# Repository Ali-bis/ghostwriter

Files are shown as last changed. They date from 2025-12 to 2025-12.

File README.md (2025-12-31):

🖋️ Ghost Writer - A Custom PCB Pen Plotter
Ghost Writer is a precision pen plotter that can be used to solve the "messy wiring" problem you usually get when you build one of those open-source plotter kits. To make that happen, I built a custom board that works with a compact - and 3D printed - parallel linkage gantry, which gives Ghost Writer high-torque motion control in a tiny footprint.

Figure 1: The Final Assembled Project, shown in CAD
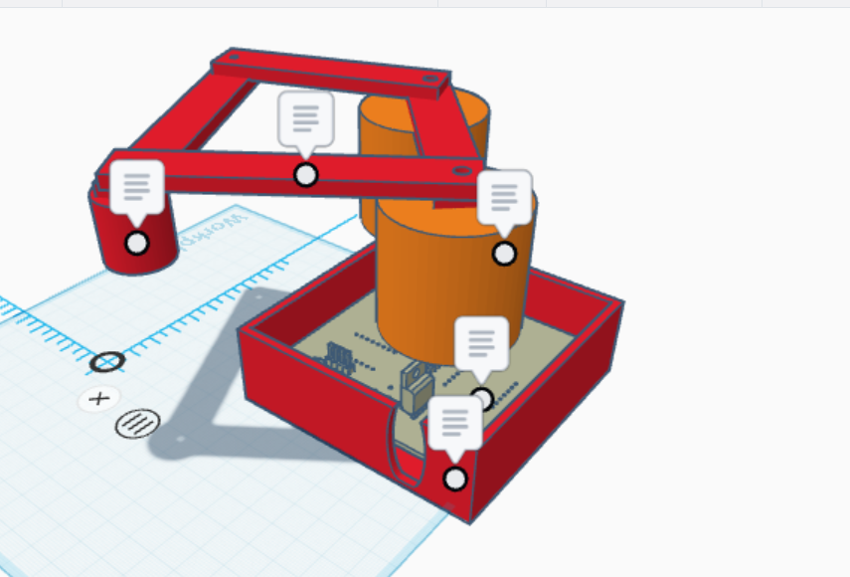
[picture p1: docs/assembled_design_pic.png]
assembled pic

assembled vid
🚀 Why I Did This
Most open-source kits have a problem with cable management and getting the electronics to work together without breaking. Ghost Writer was made to move away from the "breadboard prototype" stage and into something a bit more robust.

What I Wanted to Achieve:
No More Messy Wiring: A custom PCB means you can ditch the jumper wires and use dedicated traces for power and signal instead.
It's Super Compact: A custom 3D printed enclosure with a special cable management system keeps the whole thing at a tiny 30mm high.
It Draws Precisely: Powered by high-torque NEMA 17 steppers and a Seeed Studio XIAO (RP2040) for real-time inverse kinematics - that's a mouthful, but basically it draws very nicely.

🛠️ Hardware
Here are the key bits that make Ghost Writer tick
Main Processor: Seeed Studio XIAO RP2040 (a dual-core ARM Cortex M0+ processor)
Motion: 2x NEMA 17 Stepper Motors (each one with a 1.8° step angle for smooth movement)
Motor Drivers: 2x A4988 Stepper Drivers (these are super powerful and tuned to get the most out of the motors)
Pen Lift: a SG90 Micro Servo that you can control with a pulse-width modulation signal
Display: A tiny 0.96" I2C OLED Display so you can keep an eye on what's going on and where things are moving to
Power: 12V 2A DC via a standard barrel jack

🏗️ Mechanical Design & CAD
The enclosure was designed in Tinkercad with one main goal - stop the mechanical bits getting in the way of each other.
Carrier Board Mounting: the PCB is held in place with 9mm internal pillars which keeps it nice and insulated from the rest of the robot.
Parallel Linkage: the 80mm shoulder and 100mm forearm lengths give it a pretty generous drawing area for its size
U-Slot Management: a special cable path keeps the wiring clear of the moving parts
Figure 2: a clearance check between the custom PCB and the 3D printed housing

📂 Repository Structure
├── /hardware\
│   ├── /pcb        # the KiCad board files and Fabrication outputs (Gerbers)\
│   ├── /enclosure  # the STL files for the Box, Lid, and Linkage Arms\
│   └── /firmware   # the custom C++ validation suite (GhostWriter_Test)\
├── BOM.csv         # the Bill of Materials (itemised costs and links)\
└── README.md       # the Project documentation\

📋 Bill of Materials
The breakdown of costs and sourcing is in the BOM.csv file.
Note: This project tried to stay within a $100 budget by doing some creative 3D printing and choosing shipping methods that are pretty cost-effective

⚙️ Firmware
The system is currently running a custom C++ validation suite (GhostWriter_Test) to get the motors and servo working smoothly.
At the moment: I'm still working on getting G-Code interpretation via GRBL for RP2040 to work properly.
Motion Logic: the inverse kinematics calculations are being done on the second core of the RP2040 so the motor pulses are nice and smooth.
A Sneak Peek at the Design

Figure 2: Just to be sure - I checked to see if the PCB would fit inside the enclosure
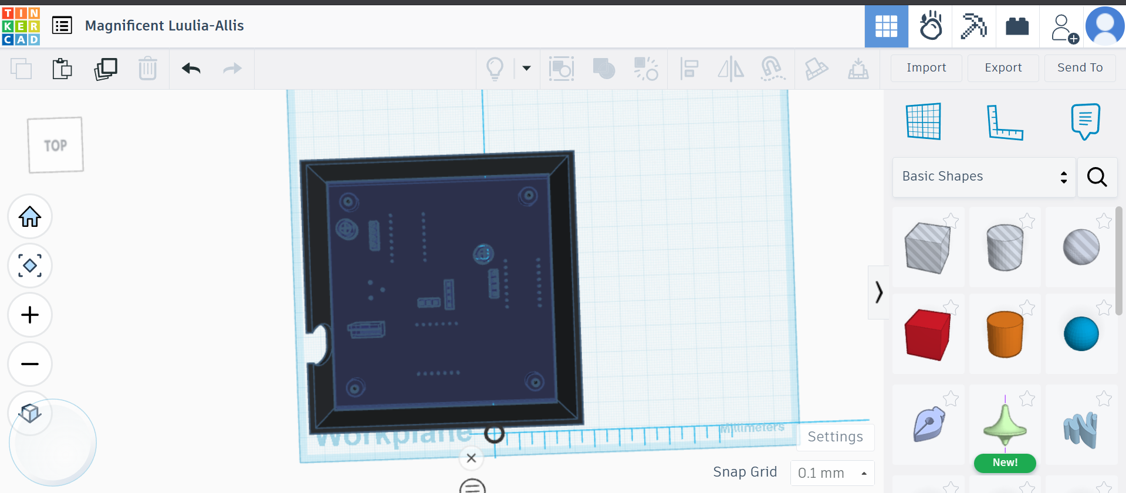
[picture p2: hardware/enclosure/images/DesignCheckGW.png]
EnclosureCheck


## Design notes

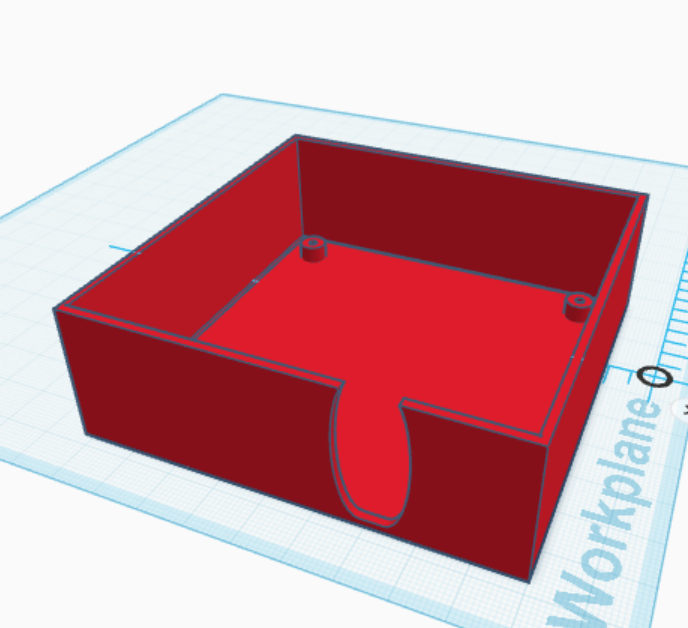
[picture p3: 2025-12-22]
docs/enclosure_design.png

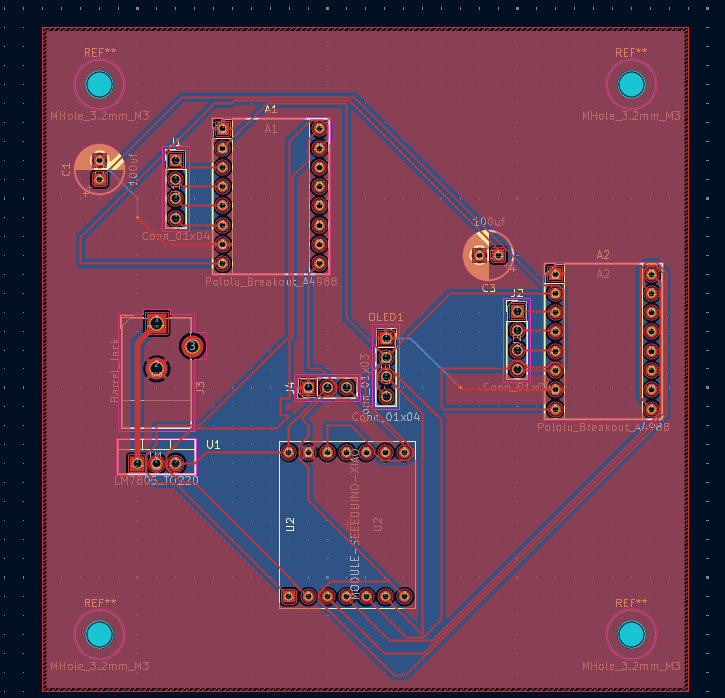
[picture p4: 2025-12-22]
docs/pcb_layout.png

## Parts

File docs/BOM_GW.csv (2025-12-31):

Item | Category | Description | Qty | Price (INR) | Sourcing Link
Seeed Studio XIAO RP2040 | Controller | Dual-core ARM Cortex M0+ | 1 | 1320 | Amazon
NEMA 17 Stepper Motors | Actuators | High Torque (Pack of 2) | 1 | 1550 | Amazon
A4988 Stepper Drivers | Electronics | With Heatsink | 2 | 598 | Amazon
0.96" I2C OLED Display | UI | 128x64 Blue/Yellow | 1 | 449 | Amazon
12V 2A DC Adapter | Power | Barrel Jack Supply | 1 | 299 | Amazon
SG90 Micro Servo | Actuator | 9g Pen-lift (Pack of 2) | 1 | 319 | Amazon
M3/M4/M5 Hardware Kit | Mechanical | Stainless Steel (280 pcs) | 1 | 1150 | Amazon
Themisto TH-B400 | Prototyping | 400 Tie Point Breadboard | 1 | 158 | Amazon
Jumper Wire Set | Wiring | 120 pcs (MM/MF/FF) | 1 | 198 | Amazon
Custom PCB | PCB | Fabricated by Lion Circuits | 1 | 1589 | Lion Circuits
DC Barrel Jack Adapter | Power | Female to Screw Terminal | 1 | 50 | Amazon
 |  | TOTAL |  | ₹8278

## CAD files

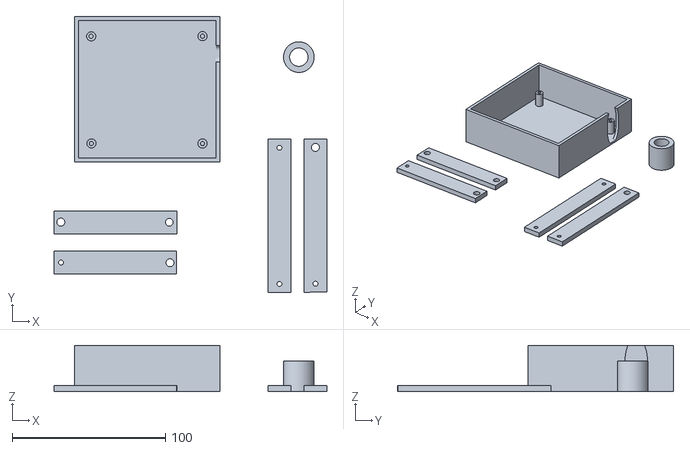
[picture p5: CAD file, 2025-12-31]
hardware/enclosure/stl/ghostwriter parts flat.stl
178.0 x 179.9 x 30.0

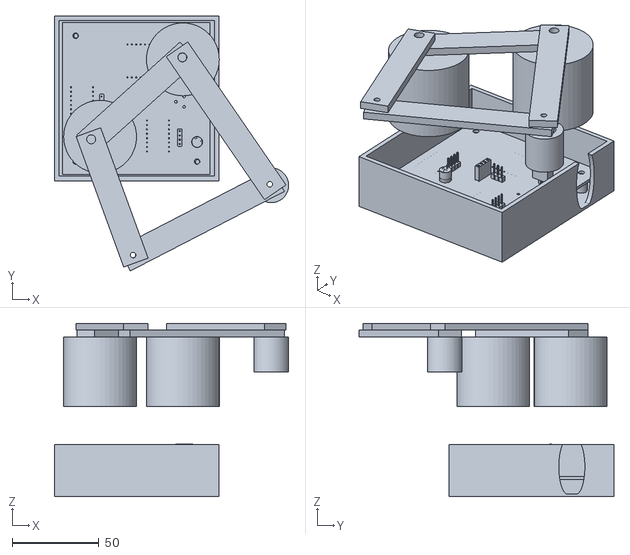
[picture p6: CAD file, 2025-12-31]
hardware/enclosure/stl/Final_design_GW (NOT TO BE PRINTED - ONLY REF OF FINAL MODEL) .stl
135.1 x 147.0 x 100.0

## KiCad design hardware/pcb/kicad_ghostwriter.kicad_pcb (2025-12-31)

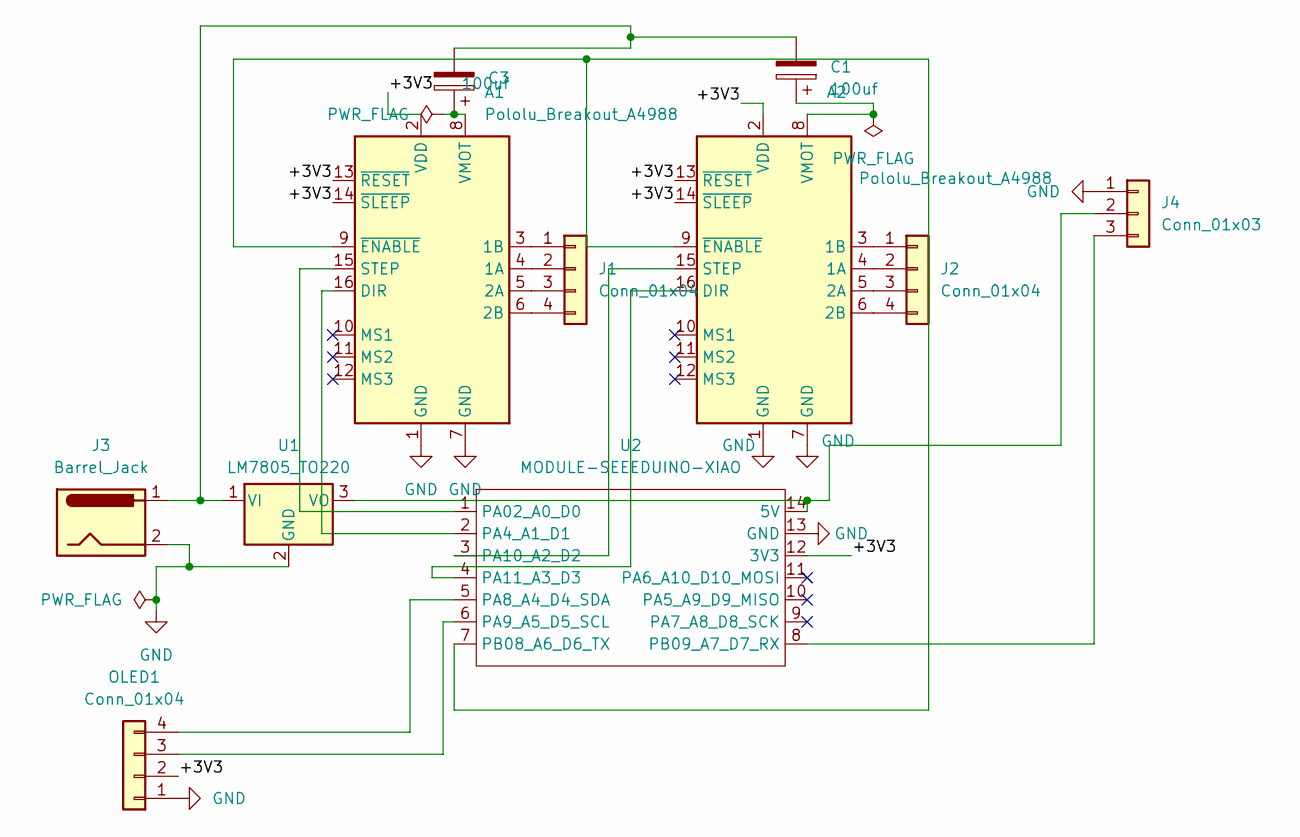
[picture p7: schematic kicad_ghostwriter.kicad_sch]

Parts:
A1, A2: Pololu_Breakout_A4988; Pololu_Breakout-16_15.2x20.3mm
C1, C3: 100uf; CP_Radial_D6.3mm_P2.50mm
J1, J2: Conn_01x04; PinHeader_1x04_P2.54mm_Vertical
J3: Barrel_Jack; BarrelJack_CUI_PJ-102AH_Horizontal
J4: Conn_01x03; PinHeader_1x03_P2.54mm_Vertical
OLED1: Conn_01x04; PinSocket_1x04_P2.54mm_Vertical
U1: LM7805_TO220; TO-220-3_Vertical
U2: MODULE-SEEEDUINO-XIAO; XIAO_RP2040_THT

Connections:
/+3V3: A1.2 (VDD), A1.13 (~RESET), A1.14 (~SLEEP), A2.2 (VDD), A2.13 (~RESET), A2.14 (~SLEEP), OLED1.2, U2.12 (3V3)
GND: A1.1 (GND), A1.7 (GND), A2.1 (GND), A2.7 (GND), J3.2, J4.1, OLED1.1, U1.2 (GND), U2.13 (GND)
unnamed: A1.4 (1A), J1.2
unnamed: A1.3 (1B), J1.1
unnamed: A1.5 (2A), J1.3
unnamed: A1.6 (2B), J1.4
unnamed: A1.16 (DIR), U2.2 (PA4_A1_D1)
unnamed: A1.15 (STEP), U2.1 (PA02_A0_D0)
unnamed: A1.8 (VMOT), C3.1
unnamed: A1.9 (~ENABLE), A2.9 (~ENABLE), U2.7 (PB08_A6_D6_TX)
unnamed: A2.4 (1A), J2.2
unnamed: A2.3 (1B), J2.1
unnamed: A2.5 (2A), J2.3
unnamed: A2.6 (2B), J2.4
unnamed: A2.16 (DIR), U2.4 (PA11_A3_D3)
unnamed: A2.15 (STEP), U2.3 (PA10_A2_D2)
unnamed: A2.8 (VMOT), C1.1
unnamed: J4.2, U1.3 (VO), U2.14 (5V)
unnamed: J4.3, U2.8 (PB09_A7_D7_RX)
unnamed: OLED1.3, U2.6 (PA9_A5_D5_SCL)
unnamed: OLED1.4, U2.5 (PA8_A4_D4_SDA)
unnamed: C1.2, C3.2, J3.1, U1.1 (VI)

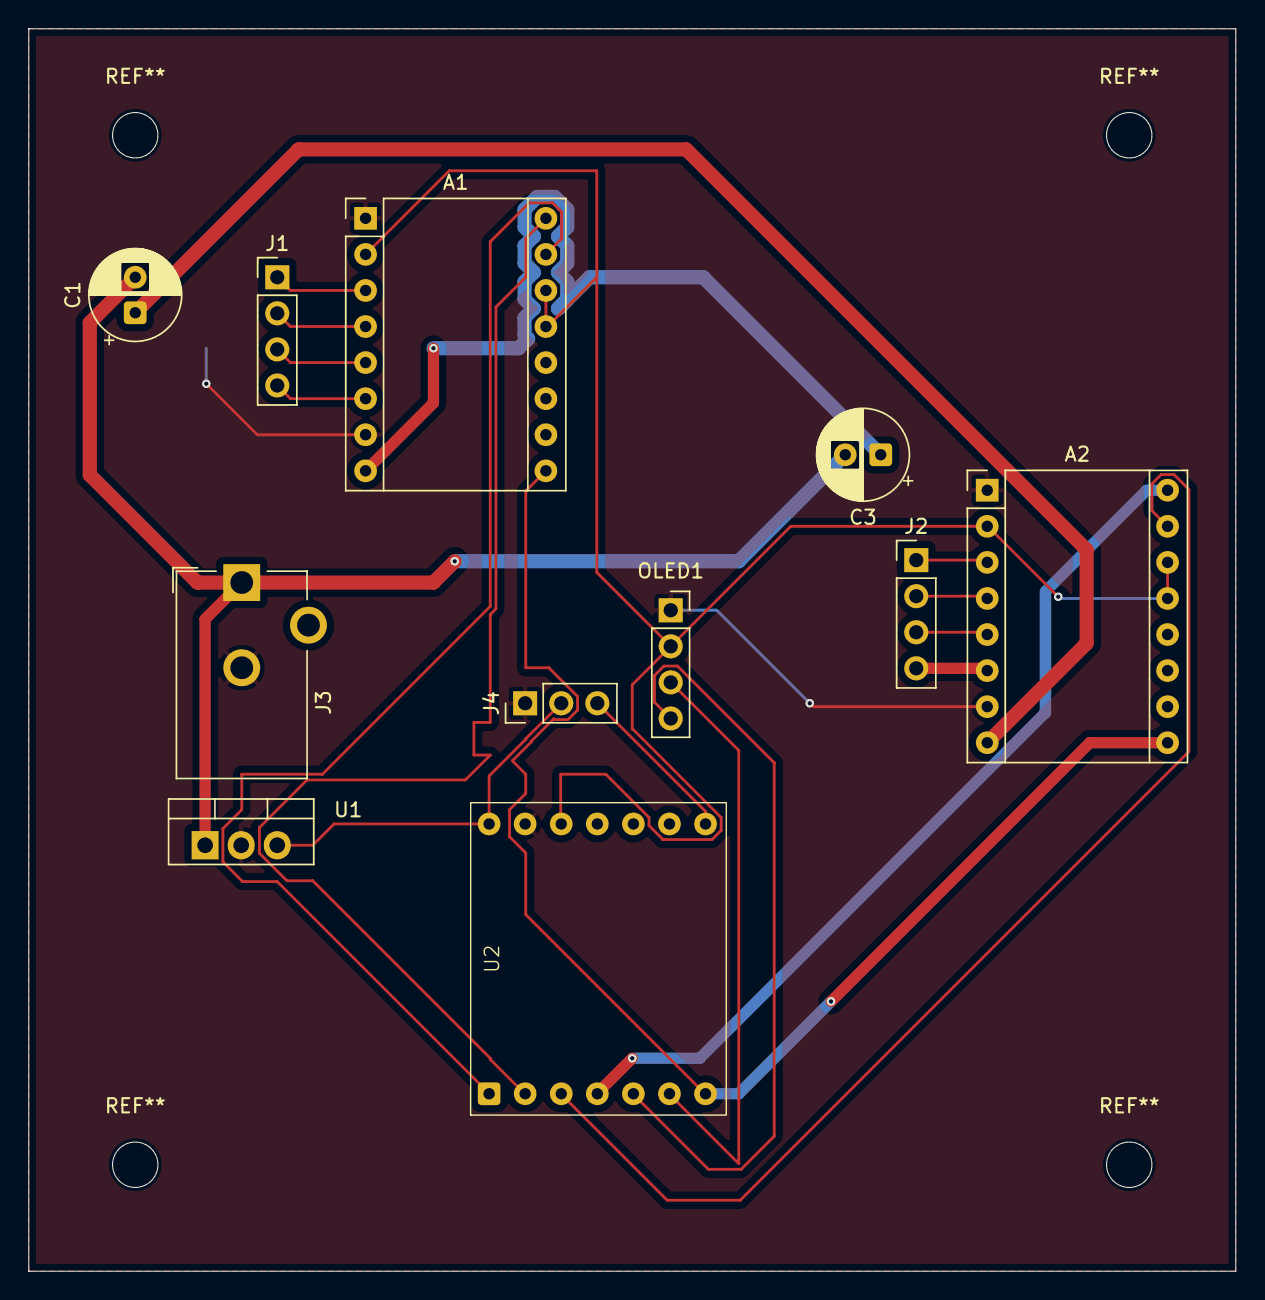
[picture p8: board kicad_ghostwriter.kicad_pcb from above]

Board: 2 copper layers, 85.0 x 87.5 mm, 11 parts (0 on the bottom side), 22 nets.

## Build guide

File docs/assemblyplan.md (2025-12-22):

Ghost Writer Assembly Guide
Phase 1: Putting the Electronics Together
PCB Time: Solder female headers onto the custom PCB carrier board 
Getting the Board Together: Press fit the Seeed Xiao into the headers
First Test: Connect the USB-C and run the 'GhostWriter_Test.ino' test file on my computer to get the motor turning around
Phase 2: Getting the Mechanicals Right
Printing the Bits
Building the Frame: Once i print all the parts, i'll assemble the corners using M3 threaded rods (or smooth rods).
Routing the Belts
Phase 3: Getting Everything Working Together
Mounting the Board: Pop the PCB into the custom standoffs in the custom "Red Box" using M2/M3 screws.
Cable Management: Get the stepper motor cables (there are four of them) into the enclosure and route them neatly through the gantry.
Adding the Pen Lift: Glue or screw the SG90 servo onto the Z-axis carriage - this will get the pen moving up and down.
Final Check: Make sure the USB-C cable can pass cleanly through the custom "U-Slot" in the enclosure wall - a bit of checking and testing before calling it done.

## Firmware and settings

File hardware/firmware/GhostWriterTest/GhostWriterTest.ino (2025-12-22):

/*
 * Ghost Writer - Test V1
 * Purpose: Just checking if the motors spin and servo moves.
 * * Hardware: 
 * - Seeed Xiao RP2040
 * - 2x Steppers (28BYJ-48)
 * - 1x Servo (SG90)
 */

#include <Servo.h>
#include <AccelStepper.h>

// --- WIRING NOTES ---
// Motor X is plugged into D0-D3
// Motor Y is plugged into D4-D7
// Servo is on D8

// NOTE: AccelStepper needs the pins in 1-3-2-4 order for these cheap motors!!
// Don't change this order or it just vibrates.
#define X_PIN1 0 
#define X_PIN2 1 
#define X_PIN3 2 
#define X_PIN4 3 

#define Y_PIN1 4 
#define Y_PIN2 5 
#define Y_PIN3 6 
#define Y_PIN4 7 

#define SERVO_PIN 8

// --- SETTINGS ---
// 8 = HALF4WIRE mode (best for 28byj-48)
#define MOTOR_TYPE 8 

// TODO: Tune these speeds later. 1000 seems safe for now.
float speed = 800.0; 
float accel = 500.0;

// Pen angles
int UP_POS = 90;
int DOWN_POS = 15; // tweaked this, 10 was hitting the paper too hard

// Objects
// passing pins as 1-3-2-4
AccelStepper stepperX(MOTOR_TYPE, X_PIN1, X_PIN3, X_PIN2, X_PIN4);
AccelStepper stepperY(MOTOR_TYPE, Y_PIN1, Y_PIN3, Y_PIN2, Y_PIN4);
Servo myServo;

void setup() {
  Serial.begin(115200);
  delay(1000); // give me time to open the monitor
  Serial.println("Ghost Writer System Test...");

  // Setup Servo first so pen doesn't drag
  myServo.attach(SERVO_PIN);
  Serial.println("Lifting pen...");
  penUp();

  // Setup Motors
  stepperX.setMaxSpeed(speed);
  stepperX.setAcceleration(accel);
  
  stepperY.setMaxSpeed(speed);
  stepperY.setAcceleration(accel);

  Serial.println("Setup done. Waiting 2s...");
  delay(2000);
}

void loop() {
  Serial.println("Starting square test...");
  
  // Draw a 5x5cm box (approx)
  // 2048 steps is roughly one full revolution of the motor shaft
  
  // Move Right
  penDown();
  runToPosition(2048, 0); 
  
  // Move Down
  runToPosition(2048, 2048); 
  
  // Move Left
  runToPosition(0, 2048); 
  
  // Move Up (Home)
  runToPosition(0, 0); 
  
  penUp();
  Serial.println("Test complete. Sleeping.");
  
  // Stop everything
  while(true) {
    delay(100); 
  }
}

// Helper to save typing
void runToPosition(long x, long y) {
  stepperX.moveTo(x);
  stepperY.moveTo(y);
  
  // block until we get there
  while (stepperX.distanceToGo() != 0 || stepperY.distanceToGo() != 0) {
    stepperX.run();
    stepperY.run();
  }
}

void penUp() {
  myServo.write(UP_POS);
  delay(200); // wait for servo to get there
}

void penDown() {
  myServo.write(DOWN_POS);
  delay(200);
}

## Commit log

2025-12-22 Update and rename hi to assemblypla.md
2025-12-23 Update and rename bill_of_materials.md to BOM.md
2025-12-31 Rename Final_design_GW.stl to Final_design_GW (NOT TO BE PRINTED - ONLY REF OF FINAL MODEL) .stl
    [Final_design_GW (NOT TO BE PRINTED - ONLY REF OF FINAL MODEL) .stl]
2025-12-31 Rename GW assembled vid.mp4 to GW_assembled_vid.mp4
